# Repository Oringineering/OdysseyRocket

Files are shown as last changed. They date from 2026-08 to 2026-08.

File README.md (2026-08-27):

# Odyssey Rocket

The Odyssey Rocket is a model rocket designed around accessibility, experimentation, and hands-on engineering! Built using household materials, commercially available components, and custom-made parts, it is the perfect project for aspiring engineers without the need for highly specialised equipment. 

The possibilities are endless! This model can be constructed as a relatively low-cost rocket, with the option to incorporate the Orion Flight Computer module capable of recording flight data such as atmospheric pressure and altitude. This modular approach allows the rocket to remain accessible to beginners, whilst giving them the opportunity to develop advanced skills valuable to the workplace that are FREE for students such as SolidWorks*, KiCad, and OpenRocket.



---

## Table of Contents

- [Features](#features)
- [System Architecture](#system-architecture)
- [Components](#components)
- [Quickstart](#quickstart)
- [PCB Design](#pcb-design)
- [Bill of Materials](#bill-of-materials)
- [Project Status](#project-status)
- [Credits](#credits)

---

## Features

- The Orion Flight Computer, a custom nose-cone-mounted PCB that will log acceleration (IMU) and altitude (barometer) data to an onboard MicroSD card, with static-pressure vent holes allowing the BMP388 to measure external atmospheric pressure accurately.
- 3D-printed PLA von Kármán ogive nose cone, custom-fit to a 660 × 60 mm AusPost postal tube body, with a 55 mm shoulder designed to fit securely within the body tube.
- Designed to remain within applicable Western Australian model-rocket operating limits, including a maximum launch mass of 500 g, no more than 25 g of propellant, operation within 5 km of an aerodrome, and an apogee not exceeding 400 ft (121.92 m).

## System Architecture

The Odyssey Rocket consists of several major subsystems:

```text
ODYSSEY ROCKET

├── Airframe
│   ├── Body tube
│   ├── Nose cone
│   └── Fins
│
├── Recovery System
│   ├── Parachute
│   ├── Shock cord
│   └── Nose-cone attachment
│
├── Propulsion
│   └── Commercial model rocket motor
│
└── Orion Flight Computer
    ├── Nose-cone avionics bay
    ├── Static-pressure vent holes
    ├── Arduino Nano
    ├── MPU6050
    ├── BMP388
    ├── MicroSD storage
    └── Power regulation

```

## Components

### Airframe
- AusPost 660 × 60 mm postal tube
- 3D-printed PLA von Kármán nose cone
- Plywood fins

### Recovery System
- Parachute
- Shock cord
- Nose-cone recovery attachment

### Propulsion
- Commercial model rocket motor

 > **Funding Note:** Rocket motors are excluded from the current funding request. The Estes E12-4 remains the selected propulsion option for the OpenRocket design and simulations but will be supplied separately.

### Orion Flight Computer
- Arduino Nano v3
- Adafruit MPU6050
- Adafruit BMP388
- Adafruit MicroSD breakout
- Pololu S13V10F5 5 V step-up/step-down voltage regulator
- Custom Orion Flight Computer PCB
- 3D-printed nose-cone avionics housing
- Static-pressure vent holes for BMP388 atmospheric pressure measurements

### Firmware
- Sensor acquisition
- Relative altitude calculation
- Accelerometer and gyroscope logging
- MicroSD CSV logging
- Serial monitoring

## Quickstart

Odyssey currently includes two different simulations:

- the **Orion Flight Computer simulation**, which runs through Wokwi
- the **Odyssey Flight Simulation**, which runs as an interactive HTML page generated from OpenRocket flight data

---

### Orion Flight Computer Simulation

The Orion Flight Computer can currently be tested virtually using Wokwi.

This simulation is intended to validate the firmware architecture, sensor communication, altitude calculations, and MicroSD data logging before the physical avionics hardware is assembled.

#### Running the Orion Simulation

1. Go to [Wokwi](https://wokwi.com/).
2. Open or create an Arduino Nano project.
3. Use the files contained in the [`FIRMWARE`](FIRMWARE/) folder.
4. Load the supplied:
   - `sketch.ino`
   - `diagram.json`
   - `libraries.txt`
5. Start the simulation using the green play button.
6. Open the Serial Monitor.
7. Orion will initialise the simulated sensors and MicroSD card.
8. Sensor measurements and calculated flight data will begin updating.

A successful startup should produce output similar to:

```text
================================
   ORION FLIGHT COMPUTER
      WOKWI PROTOTYPE
================================

MPU6050: OK
BMP180:  OK
SD Card: OK

Orion ready.
```

> **Note:** The Wokwi simulation uses a BMP180 as a substitute for the BMP388 intended for the final Orion Flight Computer.

Further information can be found in the [Firmware documentation](FIRMWARE/README.md).

---
### Odyssey Rocket Flight Simulation

The Odyssey Rocket Flight Simulation is an interactive browser-based replay generated from the current OpenRocket flight data.

[**Launch the Odyssey Rocket Flight Simulation**](https://oringineering.github.io/OdysseyRocket/SIMULATION/)

The simulation displays:

- Altitude
- Total velocity
- Vertical velocity
- Acceleration
- Thrust
- Lateral distance
- Liftoff
- Motor burnout
- Apogee
- Recovery deployment
- Ground impact

It also includes:

- Play and pause controls
- Restart control
- Timeline scrubbing
- Live flight values
- Flight-event tracking

No additional software is required. The simulation runs directly in a modern web browser.

> **Note:** The Odyssey Rocket Flight Simulation is a visual replay of OpenRocket-generated simulation data. It does not represent measured data from a physical launch.

---

#### Running the Flight Simulation Locally

The simulation can also be run locally.

1. Download or clone the Odyssey Rocket repository.
2. Open the `SIMULATION` folder.
3. Locate `index.html`.
4. Double-click the file.

The simulation should automatically open in your default web browser.

Because the simulation is completely self-contained, it does not require an internet connection once the repository has been downloaded.

## PCB Design
See the [PCB](PCB/Documentation/PCB_OFC_2026-08-23.pdf) and the [Documentation](PCB/Documentation) folder for relevant information.

## Bill of Materials
See [BOM](BOM/) for more information.

## Project Status
AWAITING FUNDING

## Credits
- Niles55 (Reddit) for his tool on modelling Nose Cones. This served as inspiration for me to pursue the Von Karman Ogive after discerning its properties.
- HTM Workshop (YouTube) for his "KiCad Tutorial | Beginning to End" series that gave me a comprehensive understanding on how to make schematics and PCBs. 
- Amazing Automation (YouTube) for his guide on how to place a logo/decal on a PCB.
- LiterallySaltwater (Discord) for providing assistance with coding
- My Dad for his endless knowledge and support :)

*SolidWorks is free for students with an education email address

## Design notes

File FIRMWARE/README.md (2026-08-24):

# Orion Flight Computer Firmware

This folder contains the firmware developed for the **Orion Flight Computer**, the avionics system (+PCB) used in the Odyssey Rocket project.

The firmware is responsible for collecting flight data from the onboard sensors such as altitude, and storing the recorded data on a MicroSD card for later analysis.

The current version has been tested virtually using Wokwi while the physical avionics components are awaiting procurement (subject to funding).

---

## Current Prototype

The current (Wowki) firmware prototype uses:

- **Arduino Nano v3**
  - Runs the Orion firmware and manages sensor communication and data logging

- **MPU6050**
  - 3-axis accelerometer
  - 3-axis gyroscope
  - Communicates with the Arduino using I²C

- **BMP180**
  - Barometric pressure and temperature sensor
  - Used only in the Wokwi simulation
  - Provides pressure data used to calculate relative altitude

- **MicroSD Card Module**
  - Stores flight data as a CSV file
  - Communicates with the Arduino using SPI

> **Note:** The BMP180 is only being used as a simulation substitute because the BMP388 is not currently available as a standard Wokwi component.

---

## Final Hardware

The intended Orion Flight Computer hardware uses:

- Arduino Nano v3
- Adafruit MPU6050
- Adafruit BMP388
- Adafruit MicroSD breakout
- Pololu S13V10F5 5 V step-up/step-down voltage regulator

The BMP388 will replace the BMP180 used in the simulation.

The Pololu regulator and other power components are not represented in the Wokwi simulation because the current simulation is intended primarily to validate the firmware and data flow.

---

## Firmware Functions

The current firmware performs the following functions:

- Initialises the MPU6050
- Initialises the barometric pressure sensor
- Initialises the MicroSD card
- Establishes a reference altitude during startup
- Reads acceleration in the X, Y and Z directions
- Reads angular velocity from the gyroscope
- Reads atmospheric pressure
- Reads temperature
- Calculates relative altitude
- Outputs live data through the Serial Monitor
- Records flight data to a CSV file
- Periodically flushes data to the MicroSD card to reduce the risk of data loss

---

## Data Flow

The Orion firmware follows the general data flow shown below:

```text
MPU6050 ─────────────┐
                     │
Barometer ───────────┼──> Arduino Nano
                     │        │
                     │        ├──> Flight calculations
                     │        │
                     │        ├──> Serial Monitor
                     │        │
                     │        └──> MicroSD Card
                     │
Power System ────────┘

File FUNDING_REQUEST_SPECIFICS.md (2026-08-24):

# Funding Breakdown
----

| Cost category | USD |
| -- | --: |
| Electronic components | **$43.78** |
| Bare PCB order | **$12.00** |
| Component/PCB shipping + VAT | **$87.54** |
| Estes E12-4 (motor) + Australian postage | **$50.91** |
| Parachute | **$15.00** |
| **Overall total so far** | **$209.23 USD** |

>**DISCLAIMER**:
A majority of these parts are accessible from the US only and that even despite the tariffs and shipping, the US providers are cheaper than the Australian providers upon closer inspection. As such, the shipping and tariffs appear extortionate on paper but compared to the Australian parts that I would have to source interstate, they are cheaper than sourcing them locally. 

----

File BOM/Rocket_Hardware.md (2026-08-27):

| No. | Qty | Comment | Specification | Manufacturer / Supplier | Supplier Part | Notes |
| --: | --: | --- | --- | --- | --- | ----- |
| 1 | 1 | Australia Post Mailing Tube with Sleeve | 660 × 60 mm | Australia Post | Mailing Tube with Sleeve Kraft Medium | Main rocket body |
| 2 | 1 | M6 RivNut | M6 threaded insert | Kincrome / Bunnings | Kincrome M6 20 Piece RivNut Set | Installed into the reinforced nose-cone bulkhead as the recovery attachment insert |
| 3 | 1 | M6 Eye Nut | M6 | Pinnacle / Bunnings | Pinnacle M6 Eye Nut | Threads into the M6 RivNut and provides the shock-cord attachment point |
| 4 | 1 | Premium BC Grade Plywood Sheet | 1200 × 810 × 3 mm | Bunnings | Project Panel Plywood | Used for fins and centering ring; 3 mm thickness matches the current OpenRocket design |
| 5 | 1 | SkyAngle Classic 20 Parachute | 20 in / 50.8 cm | SkyAngle / CS Rocketry | SkyAngle Classic 20 | Primary recovery parachute |
| 6 | 1| Shock Cord | 3 mm diameter | eBay | 3 mm Shock Cord | Connects the nose cone, parachute, and rocket body recovery assembly |

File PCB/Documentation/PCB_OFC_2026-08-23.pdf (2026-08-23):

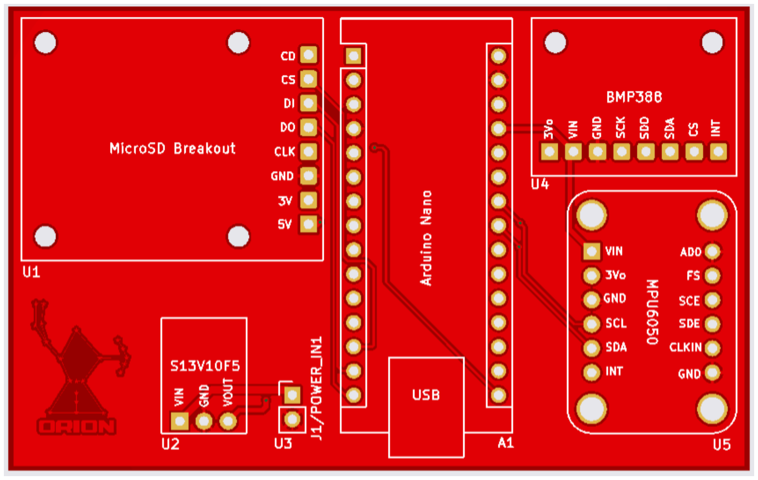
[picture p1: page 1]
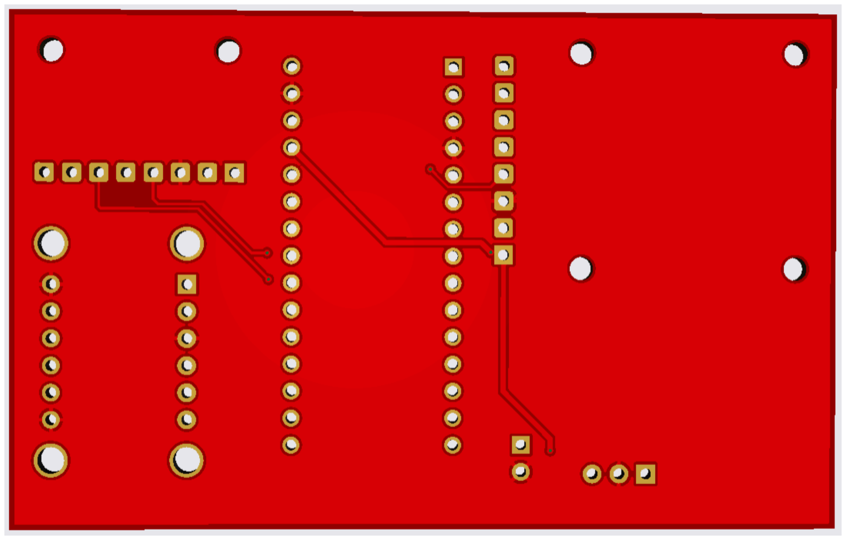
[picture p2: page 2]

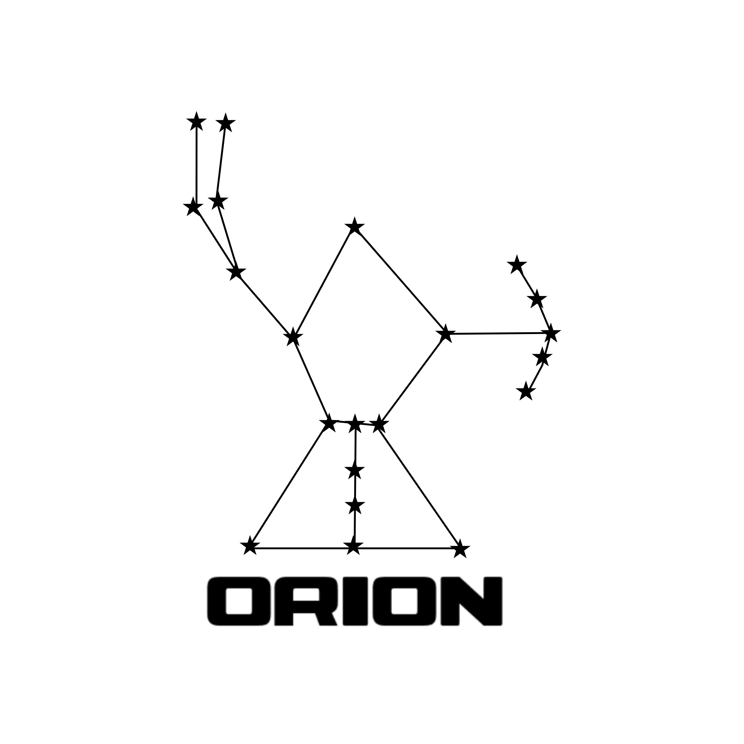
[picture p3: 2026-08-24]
ASSETS/orion.png

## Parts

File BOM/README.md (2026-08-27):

# Odyssey Rocket Bill of Materials

The estimated total cost of the Odyssey Rocket, including the Orion Flight Computer, PCB fabrication, propulsion system, recovery system, primary rocket hardware, and shipping costs, is approximately:

# **US$250**

| Item | Cost |
|---|---:|
| Orion electronic components | US$54.65 |
| Orion PCB fabrication | US$12.00 |
| Electronics / PCB shipping and VAT | US$87.54 |
| Australia Post 660 × 60 mm postal tube | ~US$3.60 |
| 3 mm plywood sheet | ~US$13.60 |
| SkyAngle Classic 20 in parachute | US$20.00 |
| 3.5 m shock cord | ~US$6.40 |
| Kincrome M6 RivNut set | ~US$9.40 |
| Pinnacle M6 eye nut | ~US$0.86 |
| Hardware shipping costs | ~US$46.00 |
| **Estimated Total Project Cost** | **~US$250** |

Prices may vary depending on supplier availability, shipping costs, and exchange rates.
~ Excludes Rocket Motor (will supply myself with one)

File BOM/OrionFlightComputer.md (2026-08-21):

| No. | Qty | Comment | Designator | Footprint | Value | Manufacturer Part | Manufacturer | Supplier Part | Supplier |
| --: | --: | --- | --- | --- | --- | --- | --- | --- | --- |
| 1 | 1 | Arduino Nano v3 | **A1** | `Arduino_Nano_v3.x_MODIFIED` | Arduino Nano | **A000005** | Arduino | A000005 | Arduino  |
| 2 | 1 | MicroSD Card Breakout Board | **U1** | `ADAFRUIT_MICROSD` | MicroSD Breakout | **254** | Adafruit | 254 | Adafruit |
| 3 | 1 | 5 V Step-Up/Step-Down Regulator | **U2** | `POLOLU_S13V10F5` | S13V10F5 | **4083** | Pololu | 4083 | Pololu |
| 4 | 1 | BMP388 Barometric Pressure Sensor Breakout | **U3** | `ADAFRUIT_BMP388` | BMP388 | **3966** | Adafruit | 3966 | Adafruit |
| 5 | 1 | MPU6050 Accelerometer/Gyroscope Breakout | **U4** | `ADAFRUIT_MPU6050` | MPU6050 | **3886** | Adafruit | 3886 | Adafruit |
| 6 | 1 | 2-pin 2.54 mm Power Input Header | **J1** | `PinHeader_1x02_P2.54mm_Vertical`* | 1×02 2.54 mm | **B-2100S02P-A110** | Ckmtw | **C124375** | LCSC |

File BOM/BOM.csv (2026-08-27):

 | Item Name | Qty | Price (total) (USD) | Item link | Notes
0 | Arduino Nano v3 (A000005) | 1 | 14.30 | https://www.amazon.com.au/Arduino-Elegoo-ATmega328P-Without-Compatible/dp/B077272KMZ/ | Main Orion Flight Computer microcontroller.
1 | Adafruit MPU6050 (Product 3886) | 1 | 12.95 | https://www.adafruit.com/product/3886 | 6-DoF accelerometer and gyroscope for Orion.
2 | Adafruit BMP388 (Product 3966) | 1 | 9.95 | https://www.adafruit.com/product/3966 | Barometric pressure sensor / altimeter for Orion.
3 | Adafruit MicroSD Card Breakout Board+ (Product 254) | 1 | 7.50 | https://www.adafruit.com/product/254 | MicroSD flight-data logging module.
4 | Pololu S13V10F5 5V Step-Up/Step-Down Regulator | 1 | 9.95 | https://www.pololu.com/product/4083 | 5 V regulator for Orion Flight Computer.
5 | Orion Flight Computer PCB fabrication | 1 | 12.00 | https://jlcpcb.com/ | Bare 2-layer PCB fabrication estimate.
6 | Electronics / PCB shipping and VAT | 1 | 87.54 |  | Combined shipping/VAT estimate from the current project budget.
7 | Australia Post Mailing Tube with Sleeve Kraft Medium (660 × 60 mm) | 1 | 3.60 | https://auspost.com.au/shop/product/mailing-tube-with-sleeve-kraft-medium-60mm-single-10005221-s | Main rocket body. Approximate USD conversion from AUD.
8 | 3 mm birch / project plywood sheet | 1 | 13.60 | https://www.bunnings.com.au/1200-x-810mm-3mm-plywood-pine-premium-bc-grade_p0340268 | Used for fins and centering ring.
9 | SkyAngle Classic 20 parachute | 1 | 20.00 | https://www.csrocketry.com/recovery-supplies/skyangle/chutes/20-skyangle-classic.html | 20 in recovery parachute.
10 | 3 mm shock cord, 3.5 m | 1 | 6.40 | https://www.ebay.com.au/itm/275682561156 | Recovery shock cord.
11 | M6 RivNut | 1 | 9.40 | https://www.bunnings.com.au/kincrome-m6-20-piece-rivnut-set_p5910351 | Final recovery attachment hardware.
12 | M6 eye fitting / eye nut | 1 | 0.86 | https://www.bunnings.com.au/pinnacle-m6-eye-nut_p0091162 | Threads into the M6 RivNut.
13 | Hardware Shipping Costs | 1 | 46.00 |  | Additional hardware shipping costs.
14 | Known Project Total (Approximate USD Value) | 1 | 250

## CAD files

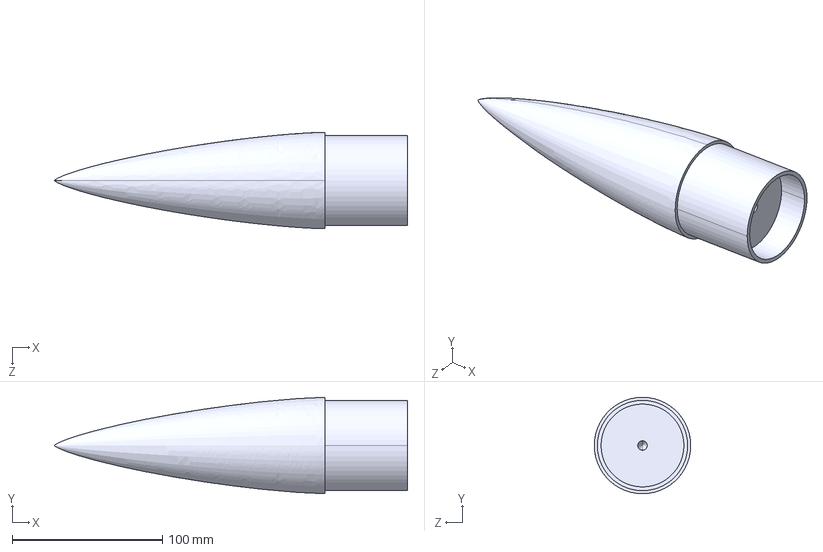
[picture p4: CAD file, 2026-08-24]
CAD/NoseCone.STEP
235.0 x 64.2 x 64.2 mm

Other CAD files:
CAD/NoseCone.SLDPRT

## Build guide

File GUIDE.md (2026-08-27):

# GUIDE

This guide outlines how to construct the **Odyssey Rocket** from scratch.

Odyssey has been designed around relatively accessible materials and components, with most custom parts either being 3D printed or manufactured using basic tools.

The **Orion Flight Computer** is optional and can be incorporated if onboard flight-data logging is desired.

> **Note:** Always follow the instructions supplied with commercially manufactured rocket motors and check the relevant local regulations before launching.

---

## 1. Required Components

Before beginning construction, gather the required components listed in the project Bills of Materials.

### Rocket Hardware

- Australia Post 660 × 60 mm postal tube
- 3 mm birch plywood sheet
- 3D-printed PLA nose cone
- M6 RivNut
- M6 eye fitting
- Shock cord
- SkyAngle Classic 20 parachute
- Estes E12-4 model rocket motor

> **Funding Note:** Rocket motors are excluded from the current funding request. The Estes E12-4 remains the selected propulsion option for the OpenRocket design and simulations but will be supplied separately.

Further information can be found in the [Rocket Hardware BOM](BOM/Rocket_Hardware.md).

### Orion Flight Computer

If the avionics system is being used, the primary components are:

- Arduino Nano v3
- Adafruit MPU6050
- Adafruit BMP388
- Adafruit MicroSD breakout
- Pololu S13V10F5 voltage regulator
- Orion Flight Computer PCB

Further information is available in the [Firmware](FIRMWARE/) and [PCB](PCB/) folders.

---

## 2. Prepare the Body Tube

The main airframe uses an **Australia Post 660 × 60 mm postal tube**.

Before attaching anything to the tube:

- Check that the tube is straight and undamaged.
- Test the fit of the nose cone shoulder.
- Mark the fin positions.
- Mark the location of the motor-mount assembly.

The nose cone should fit securely into the tube without requiring excessive force.

---

## 3. Manufacture the Fins

Odyssey uses three birch-plywood fins based on the current OpenRocket model.

### Fin Dimensions

| Parameter | Dimension |
|---|---:|
| Number of fins | 3 |
| Root chord | 70 mm |
| Tip chord | 55 mm |
| Height | 40 mm |
| Sweep length | 26 mm |
| Sweep angle | 33° |
| Thickness | 3 mm |
| Root fillet radius | 2 mm |
| Material | Birch plywood |
| Cross-section | Rounded |

The fins use **through-the-wall tabs**, allowing the fins to pass through the postal tube and connect with the internal motor-mount region.

### Fin Tab Dimensions

| Parameter | Dimension |
|---|---:|
| Tab length | 70 mm |
| Tab height | 17 mm |
| Tab position | 0 mm |
| Reference | Top of parent component |

The easiest method is to manufacture one accurate fin first and use it as a template for the remaining two.

Once all three fins have been cut, stack them together and lightly sand the edges until they are approximately identical.

The leading and trailing edges can also be rounded slightly to better represent the current OpenRocket model.

---

## 4. Mark and Cut the Fin Slots

The three fins should be evenly spaced around the body tube.

Because there are three fins:

**360° ÷ 3 = 120°**

Mark three longitudinal reference lines around the lower section of the body tube, each separated by approximately **120°**.

Using the fin tabs as a reference, mark and cut the corresponding slots through the body tube.

The slots should allow the 3 mm plywood tabs to pass through without excessive force while avoiding unnecessary clearance.

Test-fit all three fins before applying adhesive.

---

## 5. Install the Centering Ring

The motor-mount assembly uses one birch-plywood centering ring.

### Centering Ring Dimensions

| Parameter | Dimension |
|---|---:|
| Thickness | 3 mm |
| Outer diameter | 55.6 mm |
| Inner diameter | 25.8 mm |
| Material | Birch plywood |

The centering ring is positioned approximately **5 mm forward of the bottom of the motor-mount tube**.

Its purpose is to keep the motor-mount tube centred within the main airframe and provide additional support at the rear of the rocket.

Before gluing:

- Check that the inner diameter fits around the motor-mount tube.
- Check that the outer diameter fits within the main body tube.
- Confirm that the motor mount remains centred.
- Confirm that the fin tabs do not interfere with the centering ring.

Once aligned, secure the centering ring to the motor-mount assembly using an appropriate adhesive.

---

## 6. Attach the Fins

Insert each fin tab through its corresponding slot in the body tube.

Check that:

- The root chord sits flat against the outside of the body tube.
- The tab is fully inserted.
- The fin is parallel with the rocket centreline.
- The fin is not twisted.
- All three fins begin at the same axial position.
- Each fin is approximately 120° from the next.

Once satisfied with the alignment, secure the fins using an adhesive appropriate for plywood and cardboard.

A small external fillet can then be formed along each fin root.

Allow the adhesive to cure fully before continuing.

---

## 7. Print the Nose Cone

The Odyssey nose cone is a custom **von Kármán / Haack-series nose cone** created in SolidWorks.

### Nose Cone Dimensions

| Parameter | Dimension |
|---|---:|
| Nose cone length | 180 mm |
| Maximum outer diameter | 64.2 mm |
| Shoulder length | 55 mm |
| Shoulder outer diameter | 60.15 mm |
| Shoulder wall thickness | 2.5 mm |
| Internal bulkhead thickness | 7.5 mm |
| Central boss diameter | 20 mm |
| Recovery hole diameter | 6.4 mm |

The nose cone should be printed vertically with the **shoulder placed on the build plate and the nose tip facing upward**.

The current model was prepared using a **0.16 mm layer height**.

Support should be generated underneath the internal bulkhead. A support blocker can be used around the central recovery attachment so that unnecessary support material does not fill the attachment region.

Once printing is complete, inspect the nose cone for:

- Layer separation
- Cracks
- Incomplete walls
- Poorly formed support surfaces
- Damage around the internal bulkhead
- Damage around the central boss
- Poor fit between the shoulder and body tube

The shoulder should fit securely within the postal tube without requiring excessive force.

If the Orion Flight Computer is being installed, the nose cone must also provide sufficient internal clearance for the avionics housing and static-pressure vent holes described later in this guide.

---

## 8. Install the Recovery Attachment

The nose cone contains a reinforced internal recovery structure consisting of:

- A 7.5 mm internal bulkhead
- A central reinforced boss
- Four reinforcing ribs
- A central recovery hole

An earlier design considered embedding an eye bolt during the 3D-printing process.

This was abandoned because the bolt would have needed to be inserted from underneath while the shoulder remained fixed to the build plate. The metal fastener could also have interfered with the moving print head.

The final design instead uses an **M6 RivNut** installed after printing.

### Installing the M6 RivNut

The current CAD hole is approximately **Ø6.4 mm**.

This is suitable for M6 bolt clearance, but the outside diameter of an M6 RivNut is larger. The printed hole must therefore be carefully enlarged after printing.

> **Important:** The required hole diameter depends on the specific M6 RivNut being used. Measure the selected RivNut or follow the manufacturer's recommended installation-hole diameter before drilling.

Enlarge the hole gradually and keep the drill centred through the boss and bulkhead.

Once the hole has been prepared:

1. Insert the M6 RivNut.
2. Install it using a suitable RivNut setting tool.
3. Confirm that it is seated firmly against the printed boss.
4. Thread the M6 eye fitting into the RivNut.
5. Tighten it securely without applying enough force to crack or crush the PLA.

The finished attachment should be manually pull-tested before flight.

---

## 9. Install the Shock Cord

The current OpenRocket model specifies a shock-cord length of:

**350 cm (3.5 m)**

The current simulation specifies approximately **2 mm round elastic cord**.

Attach one end of the shock cord securely to the **M6 eye fitting** installed in the nose cone.

Ensure that:

- The attachment is secure.
- The cord is not damaged or frayed.
- The cord does not rub against sharp edges.
- There is enough length for the nose cone and recovery system to separate safely.

If a different diameter or material is used in the finished rocket, update the OpenRocket model accordingly.

---

## 10. Attach the Parachute

The current recovery system uses a:

**SkyAngle Classic 20**

with an approximate diameter of:

**20 in / 50.8 cm**

The recovery arrangement is approximately:

```text
Nose Cone
    │
M6 RivNut
    │
M6 Eye Fitting
    │
Shock Cord
    │
Parachute Attachment
    │
Rocket Body
```

Attach the parachute fitting securely to the shock-cord recovery assembly.

Before packing the parachute:

- Check that the suspension lines are not tangled.
- Inspect the canopy for damage.
- Confirm that all attachment points are secure.
- Make sure the parachute opens freely.
- Confirm that the packed parachute fits within the body tube without excessive compression.

---

## 11. Motor System

The current OpenRocket configuration uses an:

**Estes E12-4**

This is a commercially manufactured 24 mm model rocket motor with a four-second delay.

The motor should only be installed when the completed rocket is being prepared for launch.

Follow the manufacturer's instructions for installation, retention and ignition.

---

## 12. Assemble the Orion Flight Computer

The Orion Flight Computer is an optional avionics subsystem designed to record flight data for post-flight analysis.

The PCB integrates:

- Arduino Nano v3
- Adafruit MPU6050
- Adafruit BMP388
- Adafruit MicroSD breakout
- Pololu S13V10F5 voltage regulator
- Power input connector

PCB design and manufacturing information can be found in the [PCB](PCB/) folder.

### PCB Manufacturing

The bare PCB can be manufactured using the fabrication files included in the repository.

If only **bare PCB manufacturing** is selected when ordering the board, the modules and connectors must be installed manually once the PCB arrives.

If an appropriate assembly service has been configured with the manufacturer, some components may instead arrive pre-assembled.

The current Orion design primarily uses modules and through-hole headers and is therefore suitable for manual assembly.

### Component Placement

| Designator | Component |
|---|---|
| A1 | Arduino Nano v3 |
| U1 | Adafruit MicroSD breakout |
| U2 | Pololu S13V10F5 regulator |
| U3 | Adafruit BMP388 |
| U4 | Adafruit MPU6050 |
| J1 | Power input header |

Before soldering:

- Confirm that each component matches its intended footprint.
- Check component orientation.
- Ensure that header pins pass cleanly through the PCB.
- Make sure each module sits level.
- Check that nothing has been inserted backwards.

### Soldering

Unless the PCB has been supplied with the required hardware already assembled, the modules and headers must be soldered manually.

For each connection:

1. Insert the component or header.
2. Confirm its orientation.
3. Hold the component square to the PCB.
4. Heat both the pad and pin with the soldering iron.
5. Feed a small amount of solder into the joint.
6. Remove the solder.
7. Remove the iron.
8. Allow the joint to cool without moving the component.

Inspect the completed PCB for:

- Missing joints
- Poor wetting
- Excess solder
- Solder bridges
- Loose pins
- Incorrect component orientation

Do not connect a battery until the PCB has been inspected.

---

## 13. Bench Test the Orion Flight Computer

The Orion Flight Computer should be tested using a computer and USB connection **before testing the battery and Pololu power system**.

USB is useful for the first testing stage because it provides both power and serial communication with the Arduino Nano.

### Required Equipment

- Completed Orion PCB
- Arduino Nano
- Computer
- USB data cable
- MicroSD card
- Arduino IDE
- Orion firmware

> **Important:** Make sure the USB cable supports data transfer. Some cables only provide power.

### Step 1 - Inspect the PCB

Before connecting USB:

- Inspect both sides of the PCB.
- Check for solder bridges.
- Check for loose solder fragments.
- Confirm that all modules are installed in the correct orientation.
- Check the power rails for obvious shorts using a multimeter where possible.

Do not connect the external battery at this stage.

### Step 2 - Connect the Nano Using USB

Connect the Arduino Nano directly to the computer.

During this stage, USB provides power and serial communication.

Avoid connecting the external battery simultaneously until the final power architecture has been properly verified.

### Step 3 - Configure Arduino IDE

Open Arduino IDE.

Select:

**Tools → Board → Arduino Nano**

Select the appropriate processor and then select the Nano's serial port under:

**Tools → Port**

### Step 4 - Test the Nano and Serial Connection

Upload a simple serial-output sketch.

Open:

**Tools → Serial Monitor**

The current Orion firmware uses:

**115200 baud**

Confirm that the Nano can send data reliably to the computer.

### Step 5 - Test the I²C Bus

The MPU6050 and BMP388 share the I²C bus.

Run an I²C scanner and confirm that both sensors are detected.

This provides a basic check of:

- SDA
- SCL
- Sensor power
- Ground
- I²C communication

### Step 6 - Test the MPU6050

Run a basic MPU6050 test and confirm that the following values appear:

- X acceleration
- Y acceleration
- Z acceleration
- X angular velocity
- Y angular velocity
- Z angular velocity

Move and rotate the PCB and confirm that the values change accordingly.

### Step 7 - Test the BMP388

Run a BMP388 test and confirm that the following values are available:

- Atmospheric pressure
- Temperature
- Calculated altitude

The measurements should remain reasonably stable when the PCB is stationary.

### Step 8 - Test the MicroSD Card

Insert a formatted MicroSD card.

Run an SD test that:

1. Initialises the card.
2. Creates a test file.
3. Writes several lines.
4. Closes the file.

Remove the card and check the file on the computer.

### Step 9 - Upload the Complete Orion Firmware

Once each subsystem works independently, upload the complete Orion firmware.

A successful startup should produce output similar to:

```text
================================
   ORION FLIGHT COMPUTER
================================

MPU6050: OK
BMP388:  OK
SD Card: OK

Orion ready.
```

### Step 10 - Perform a Logging Test

Allow Orion to run for several minutes.

During the test:

- Move and rotate the PCB.
- Raise and lower it.
- Monitor the Serial output.
- Allow data to be recorded to the MicroSD card.

Afterward, check the generated CSV and confirm that:

- Timestamps increase correctly.
- Acceleration measurements were recorded.
- Gyroscope measurements were recorded.
- Pressure measurements were recorded.
- Altitude measurements were recorded.

### Step 11 - Test the External Power System

Once USB testing has succeeded, disconnect USB.

Connect the intended battery to the Pololu regulator.

Measure the regulator output with a multimeter before connecting the complete system.

The expected regulated output is approximately:

**5 V**

Once verified, power Orion using the intended flight power system and confirm that its behaviour matches the USB test.

---

## 14. Build the Nose-Cone Avionics Bay Housing

The Orion Flight Computer should not be installed as a bare PCB.

For Odyssey, Orion is housed within the **nose cone** using a dedicated **3D-printed avionics sled or enclosure**.

The housing should:

- Fit securely within the available internal volume of the nose cone.
- Hold the Orion PCB firmly using standoffs or spacers.
- Prevent the flight computer from moving during launch and recovery.
- Remain clear of the M6 RivNut, M6 eye fitting, internal bulkhead, and reinforcing ribs.
- Provide clearance for the MicroSD card.
- Provide clearance for the Arduino Nano USB connector where practical.
- Allow wiring to pass through without being crushed or sharply bent.
- Avoid covering the BMP388 pressure sensor.
- Remain removable for testing, maintenance, and firmware updates.

A simple removable sled is preferred over a separate PVC tube because it can be shaped specifically around the nose-cone geometry while minimising additional mass and lost internal volume.

Before finalising the housing, confirm that the complete Orion assembly fits inside the nose cone without interfering with the recovery attachment or preventing the nose cone from seating correctly in the body tube.

---

## 15. Barometer Ventilation

The Orion Flight Computer uses a **BMP388 barometric pressure sensor** to estimate altitude.

Because Orion is housed inside the nose cone, the avionics compartment must not be completely sealed. Several small **static-pressure vent holes** should therefore be added through the nose-cone wall adjacent to the avionics bay.

The vent holes should:

- Be distributed around the circumference of the nose cone where practical.
- Be positioned adjacent to the Orion avionics bay.
- Provide direct pressure equalisation between the internal avionics compartment and the surrounding atmosphere.
- Remain clear of the M6 recovery attachment, internal bulkhead, and reinforcing ribs.
- Avoid being obstructed by the avionics housing.
- Avoid locations immediately beside large protrusions or regions of heavily disturbed airflow where practical.

The vent holes should be added only after the final position of the Orion Flight Computer and its housing has been established.

These openings allow the internal pressure around the BMP388 to follow changes in external atmospheric pressure more closely, improving the accuracy of altitude measurements.

After the vent holes have been added, check that they are clean, unobstructed, and open directly into the avionics cavity.

---

## 16. Install Orion in the Nose Cone

Once the avionics housing has been assembled, bench-tested, and checked for clearance, install it securely within the nose cone.

Ensure that:

- The housing cannot move freely.
- The PCB remains fixed within the housing.
- The BMP388 remains exposed to the ventilated internal cavity.
- The static-pressure vent holes are not blocked by the housing, wiring, or PCB.
- The MicroSD card remains accessible where practical.
- Wiring cannot contact sharp edges.
- The avionics bay does not interfere with the M6 RivNut, eye fitting, internal ribs, or recovery attachment.
- The nose cone can still seat correctly within the body tube.
- The assembly can be removed for maintenance where practical.

---

## 17. Final Assembly

Once the major components have been completed, inspect the entire rocket.

Check:

- Nose cone fit
- Body tube condition
- Fin alignment
- Fin attachment
- Centering ring
- Motor mount
- RivNut recovery attachment
- Shock cord
- Parachute
- Orion nose-cone avionics bay, if installed
- Static-pressure vent holes clear and unobstructed

Nothing inside the rocket should move freely during flight.

---

## 18. Update the OpenRocket Model

The final physical rocket will differ slightly from the original OpenRocket model.

Before launch, weigh the completed rocket and update the simulation where necessary.

Important values include:

- Total mass
- Centre of gravity
- Fin geometry
- Nose cone dimensions
- Recovery-system mass
- Orion Flight Computer mass
- Motor selection

The current OpenRocket configuration shown during development produces approximately:

| Parameter | Current Simulation |
|---|---:|
| Motor | Estes E12-4 |
| Apogee | 121.28 m |
| Maximum velocity | 38.74 m/s |
| Maximum acceleration | 67.35 m/s² |
| Stability | 1.71 cal |

These values should be treated as **simulation results rather than guaranteed flight performance**.

Re-run the simulation using the final measured configuration before flight.

---

## 19. Ground Testing

Before flight, complete basic ground testing.

This should include:

- Nose cone fit testing
- Recovery attachment pull testing
- Shock-cord inspection
- Parachute deployment testing
- Structural inspection
- Orion power-on testing
- Sensor initialisation
- MicroSD logging verification
- Avionics-bay retention testing
- Static-pressure vent-hole inspection
- BMP388 pressure-response testing with Orion installed in the ventilated nose cone

The Wokwi simulation validates the general firmware architecture but does not replace testing of the physical Orion hardware.

---

## 20. Launch Preparation

Once construction, simulation and ground testing have been completed, the rocket can progress to launch preparation.

Before launching:

- Check weather conditions.
- Check applicable fire restrictions.
- Confirm that the launch location is suitable.
- Check applicable model rocket and aviation requirements.
- Inspect the rocket immediately before flight.
- Confirm that the nose-cone pressure vents remain unobstructed.
- Follow the motor manufacturer's preparation and ignition instructions.

---

# Construction Complete

At this stage, the Odyssey Rocket should be mechanically assembled and ready for final testing and launch preparation.

Additional project information is available in:

- [Main README](README.md)
- [Bill of Materials](BOM/)
- [Firmware](FIRMWARE/)
- [PCB](PCB/)
- [CAD](CAD/)

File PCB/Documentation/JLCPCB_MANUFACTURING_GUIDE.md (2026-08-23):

# JLCPCB Manufacturing Guide
----

This document outlines the process used to prepare and manufacture the Orion Flight Computer PCB through JLCPCB.

----
## Note:

The only extra thing I changed was the colour of the PCB because red suited the decal on the PCB better than the standard green did.

# 1. Final Checks in KiCad

Before generating fabrication files, ensure the PCB is complete and passes all required checks.

## Final checklist

- Run the **Design Rules Checker (DRC)** - you may experience errors such as:
  - setting silkscreen text to 0.7 mm when a larger size was preferable for manufacturing
  - isolated copper fill regions
  - inadequate thermal-relief connections
  - overly wide tracks interfering with nearby pads
  - silkscreen elements overlapping solder-mask regions

- Confirm that there are **0 unconnected items**
- Confirm that there are **0 critical violations**
- Refill all copper zones using `B`
- Check all the GND pads are properly connected to the copper pours
  - If they aren't connected, try going over the schematic or attempt a copper pour again.
- Verify all tracks are routed
- Verify track widths (different track types support different currents and typically correspond to their functionality on the PCB):
  - Signal tracks: **0.25 mm**
  - +5 V tracks: **0.50 mm**
  - VIN_RAW / main input power: **0.75 mm**
- Check silkscreen text does not overlap pads or solder-mask openings
- Check the board outline on `Edge.Cuts` is fully closed
- Inspect the design in KiCad's **3D Viewer**
- Verify the orientation of all breakout modules
- Confirm USB and MicroSD access is unobstructed
- Check all custom footprint pin mappings against the schematic

# 2. Generate Gerber Files

In KiCad PCB Editor:

**File → Fabrication Outputs → Gerbers (.gbr)**

Select the required layers.

For this 2-layer PCB, the important layers are typically:

- `F.Cu`
- `B.Cu`
- `F.SilkS`
- `B.SilkS` if used
- `F.Mask`
- `B.Mask`
- `Edge.Cuts`

Generate the Gerber files into a dedicated fabrication folder.

Example:

```text
PCB/Fabrication/Gerbers/

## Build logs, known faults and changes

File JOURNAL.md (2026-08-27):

# Odyssey Rocket

> **A model rocket prototype built from accessible materials, custom-designed components, and a completely self-developed avionics system.**

| Project Information | Details |
| --- | --- |
| **Author** | Orin Gibson |
| **Project** | Odyssey Rocket |
| **Description** | A rocket prototype... but I knew nothing about rockets or the software that can be utilised to make one. |
| **Creation Date** | 01/08/2026 |
| **Total Time Spent** | **~37 hours** |

---

# Day 1 — Learning Bit by Bit
### ⏱️ 35 minutes

I spent the first day familiarising myself with industry software such as **SolidWorks**, preparing myself for the CAD work required for components such as the nose cone and other internal components that would later be 3D printed.

<p align="center">
  
</p>

<p align="center">
  <em>Beginning the process of learning CAD and 3D modelling.</em>
</p>

---

# Day 2 — Body Schematics and Design
### ⏱️ 1 hour 39 minutes

I introduced myself to **OpenRocket**, an open-source program that lets you visualise a rocket and run simulations on it.

I managed to grasp a basic understanding of how the software works: you select the components you want for your rocket while determining the appropriateness of certain features to optimise factors such as:

- **Stability**
- **CP — Centre of Pressure**
- **CG — Centre of Gravity**
- Aerodynamic performance

Something I initially struggled with was producing a stable rocket.

From what I later discerned from [this resource on model rocket stability](https://www.spacecad.com/posts/model-rocket-stability-prediction/), my stability calibre was not optimal and was one reason why the rocket was underperforming in simulations.

I initially had a stability value above **2.8 cal**, believing that a higher calibre automatically meant a more stable rocket. However, excessive stability can also result in poorer aerodynamic behaviour.

<p align="center">
  
</p>

<p align="center">
  <em>An early OpenRocket iteration of Odyssey.</em>
</p>

---

# Day 3 — Functionality Refinements
### ⏱️ 1 hour 28 minutes

This day was spent rectifying the blunders made on Day 2.

With newfound awareness and a strong resolve to improve upon yesterday's faults, I put my head down and got working.

This [OpenRocket tutorial series](https://www.youtube.com/watch?v=oqe0lTp1WH0&list=PLulIhjxR7aZQ4coWt7MRHb4xt9wz0Fz6h) really made me think.

I had no idea about the purpose of a **shoulder**, which connects the nose cone to the rocket body, or **fin tabs**, which extend into the rocket body and provide a more secure structural connection.

With these implementations taken into consideration, my model became **far more stable**, and it was genuinely satisfying to see the design improve.

### Nose Cone Constraints

Another thing I had not considered was the length of my nose cone.

Originally, I had it set to approximately **22 × 6 cm**, but realised that if I were to use a local 3D printer, these dimensions might exceed its available build height once the **5.5 cm shoulder** was included.

A total length of approximately **27.5 cm** exceeds the build volume of many basic entry-level printers.

My original reasoning for the 22 cm nose cone was to maintain approximately a **3:1 nose-cone length-to-diameter ratio** to reduce drag. However, this was less important than I initially thought for the relatively low-speed flight regime being targeted.

<p align="center">
  
</p>

<p align="center">
  <em>Refined OpenRocket design after improving stability and dimensional constraints.</em>
</p>

With these limitations in place, I settled on a nose cone length of **18 cm**.

It will not mitigate drag to the same extent as the original design, but it remains sufficiently long for the intended application.

The total length, including the shoulder, became approximately **23.5 cm**, allowing it to fit within an entry-level 3D printer with a maximum build height around **24.5–25 cm**.

---

# Day 4 — Schematic Design
### ⏱️ 4 hours 16 minutes

I started my work on **KiCad** today.

KiCad was a completely new challenge because electronics design is far from my existing strong suit. Nonetheless, it became a journey filled with some amazing discoveries.

To begin, I watched a tutorial series explaining how to create a schematic in KiCad.

I started by assembling the individual components:

- **MPU6050 IMU**
- **Adafruit BMP388 barometer**
- **Arduino Nano v3**

For the Arduino Nano, I also modified one of the pin definitions to prevent unnecessary errors during KiCad's **Electrical Rules Check (ERC)**.

<p align="center">
  
</p>

<p align="center">
  <em>Early development of the Orion Flight Computer schematic.</em>
</p>

I felt outrageously proud because I never expected to learn this process.

It feels rather good to now be familiar with all of this new terminology and these completely unfamiliar engineering processes.

---

# Day 5 — Schematic Improvement
### ⏱️ 3 hours 33 minutes

I realised that my flight computer did not yet contain all of the components required to perform the functions I wanted.

It was missing:

- a **MicroSD module** for flight-data storage
- a **voltage regulator** for stable power distribution

The new additions consisted of:

- **Adafruit MicroSD Breakout Board+**
- **Pololu 5V Step-Up/Step-Down Voltage Regulator S13V10F5**

My reasoning for choosing these products was largely their excellent documentation and accessibility compared with alternatives that could be significantly harder to source.

## Orion Flight Computer

I also finally settled on a name:

### **Orion Flight Computer**

Why Orion?

I loved space a lot as a kid, and **Orion** happens to be remarkably close to my own name, **Orin**.

The flight computer contains:

| Component | Purpose |
| --- | --- |
| **Arduino Nano v3** | Main microcontroller |
| **MPU6050 IMU** | Acceleration and rotational measurements |
| **BMP388 Barometer** | Atmospheric pressure and altitude measurements |
| **MicroSD Module** | Flight-data logging |
| **S13V10F5 Regulator** | Voltage regulation and power management |

I based the component schematics primarily on technical designs and manufacturer documentation, including Adafruit's respective Eagle files and component repositories.

After each individual component was created, I incorporated it into the overall schematic.

This marked a successful implementation, although there were still some underlying mistakes that would need to be corrected later.

<p align="center">
  
</p>

<p align="center">
  <em>An intermediate version of the Orion Flight Computer schematic.</em>
</p>

---

# Day 6 — Schematic Finalisation
### ⏱️ 2 hours 10 minutes

I revised the individual schematics and realised that the original IMU I had selected was not documented sufficiently for me to confidently reproduce its physical dimensions.

I therefore settled on the **Adafruit MPU6050 IMU**.

This required me to redo the IMU schematic because Adafruit's breakout contains **12 pins**, with six on either side.

With the schematic finalised, I shifted my focus toward creating the individual **PCB footprints** for each component.

Each component was then refined so that the schematic could be transferred effectively into the final PCB design.

<p align="center">
  
</p>

<p align="center">
  <em>Finalised MPU6050 schematic symbol and pin configuration.</em>
</p>

---

# Day 7 — PCB Completion and Nose Cone Construction
### ⏱️ 9 hours 5 minutes

I dedicated essentially the entire day to answering two major questions:

> **How do I build a solid PCB?**

and

> **How should I design the nose cone appropriately?**

---

## Part 1 — Orion Flight Computer PCB

Starting with the PCB, I got down to business.

I learnt countless new concepts, including:

- why **wider tracks** are useful for higher-current power connections
- the purpose of **copper pours**
- how **vias** connect separate PCB copper layers
- how to avoid creating an unmanageable **ratsnest**
- PCB **Design Rules Checks (DRC)**
- appropriate component spacing and placement
- silkscreen requirements
- thermal reliefs and copper islands

Vias were particularly interesting. I like to think of them as tiny **wormholes** that take an electrical connection from one side of the PCB to the other.

I spent a significant amount of time determining the optimal component layout.

<p align="center">
  
</p>

<p align="center">
  <em>Developing the component layout for the Orion Flight Computer PCB.</em>
</p>

I settled on this layout because placing the **Arduino in the centre** allowed the surrounding components to be positioned on either side according to the pins they needed to connect to.

I also designed a small logo for the **Orion Flight Computer** in the bottom-left corner of the PCB using Canva.

I searched for an image of the Orion constellation and modelled the decal around it, which seemed particularly fitting given the name.

### Troubleshooting

A significant portion of the session involved correcting earlier schematic and footprint mistakes.

Some pin labels on components such as the **BMP388** and **MicroSD Breakout Board+** differed slightly from their manufacturer's terminology.

Examples included:

- `3V3` → `3Vo`
- `SCL` → `SCK`
- `VCC` → `VIN`

Troubleshooting took up the majority of my time.

I'd estimate that finalising the PCB consumed approximately **7 of the 9 hours** spent on the project that day.

Some notable errors included:

- setting silkscreen text to **0.7 mm** when a larger size was preferable for manufacturing
- isolated **copper fill** regions
- inadequate thermal-relief connections
- overly wide tracks interfering with nearby pads
- silkscreen elements overlapping solder-mask regions

Eventually, the Design Rules Check was cleared.

<p align="center">
  
</p>

<p align="center">
  <em>The completed Orion Flight Computer PCB design.</em>
</p>

---

## Part 2 — Nose Cone Construction

After leaving CAD alone for a while, I finally decided it was time to tackle the nose cone.

I started out thoroughly confused because I initially attempted to navigate the process with very little assistance.

Long story short, I generated a curve based on the **Haack series**, inspired by the process demonstrated by the [Rocket Component Tools calculator](https://coleandreoli-rocket-component-tools-main-blwurh.streamlit.app/).

I then created horizontal and vertical construction lines representing:

- **30 mm radius**
- **180 mm nose-cone length**

The generated Haack-series profile was revolved around the central axis to produce the three-dimensional nose cone.

I then centred a two-dimensional circle on the flat end of the revolved shape and extruded it to create the **shoulder**, allowing the nose cone to fit inside the rocket's body tube.

This ultimately produced the first physical nose-cone prototype.

---

### End-of-Day Result

By the end of Day 7:

- ✅ Orion Flight Computer PCB layout completed
- ✅ PCB Design Rules Check resolved
- ✅ Custom Orion silkscreen logo created
- ✅ Nose cone model completed
- ✅ Nose cone prepared for 3D printing
- ✅ GitHub documentation brought up to date

The rest of the session was spent organising the GitHub repository and preparing the project for the next stage.

---

# Day 8 — Nose Cone Amendments and GitHub Overhaul
### ⏱️ 5 hours 55 minutes

Today was split between two things: continuing the nose cone design and giving the GitHub repository a fairly serious overhaul.

I spent an ungodly amount of time going through the repository, cleaning up folders, reorganising documentation, updating the BOMs, and generally trying to make the project understandable to someone other than myself.

The second half of the day was spent revisiting the nose cone.

The original nose cone itself was already functional, but the recovery system still needed a proper structural attachment point. I therefore began redesigning the shoulder to include an internal recovery structure.

The updated design incorporated:

- a hollow **2.5 mm shoulder wall**
- a **7.5 mm internal bulkhead**
- a reinforced central boss
- a **Ø6.4 mm recovery hole**
- additional internal space for the recovery hardware

The main difficulty was determining how the shock cord could realistically be attached without relying on a weak section of printed PLA.

I initially considered embedding an eye bolt into the print itself, but this quickly introduced a number of manufacturing problems that would need to be resolved later.

<p align="center">
  
</p>

<p align="center">
  <em>Development of the reinforced shoulder and internal recovery structure.</em>
</p>

By the end of the day, the nose cone was significantly closer to being a genuinely usable component rather than simply a hollow aerodynamic shell.

---

# Day 9 — Nose Cone Finalisation, Firmware and Simulation
### ⏱️ 6 hours 30 minutes

Today I spent hours moiling away at SolidWorks.

The focus was finally completing the structural side of the nose cone and recovery system.

I learnt how to:

- create and apply **fillets**
- build a central **boss structure**
- create reinforcing **ribs**
- use circular patterns around a central axis
- work with multiple solid bodies
- merge the shoulder and nose cone into one printable body
- prepare the model for slicing and support generation

The final recovery structure used:

- a **7.5 mm bulkhead**
- a **Ø20 mm central boss**
- four reinforcing ribs
- a **Ø6.4 mm central recovery hole**
- filleted rib roots to reduce sharp stress concentrations

One thing that caused a fair amount of pain was the recovery fastener.

My original plan was to insert a long eye bolt while the nose cone was printing. After looking at how close and how quickly the printer head travels above the active layer, I realised that having a large metal fastener protruding into the printing area was not a particularly intelligent idea.

I therefore moved toward using an **M6 RivNut** installed after printing. The existing Ø6.4 mm hole can be carefully enlarged to match the installation diameter of the selected RivNut, allowing an M6 eye fitting to be installed after the print is complete.

<p align="center">
  
</p>

<p align="center">
  <em>Nose Cone V2.</em>
</p>

### Firmware

I also started developing the firmware for the **Orion Flight Computer**.

Because the physical components have not yet been procured, I created a virtual prototype using **Wokwi**.

The simulation used:

- Arduino Nano
- MPU6050
- BMP180
- MicroSD card

The BMP180 is used only as a stand-in for the final BMP388 because Wokwi does not currently provide the BMP388 as a standard simulated component.

After a fair amount of troubleshooting with the SD libraries and SPI wiring, I successfully got the simulation to:

- initialise the MPU6050
- initialise the BMP180
- calculate relative altitude
- initialise the MicroSD card
- create a CSV file
- record simulated flight data
- output live measurements through the Serial Monitor

Being able to manipulate the simulated atmospheric pressure and watch Orion calculate a corresponding altitude change was probably one of the most satisfying software milestones of the project.

---

# Day 10 — SHIPMENT
### ⏱️ 1 hour 33 minutes

The project is finally in a state where I am comfortable shipping it.

Today was primarily spent tying everything together.

The GitHub repository was finalised with:

- project documentation
- CAD files
- PCB files
- fabrication documentation
- firmware
- Wokwi simulation files
- Bills of Materials
- construction guide
- project journal

I also finalised the most recent OpenRocket configuration.

The current simulation produces approximately:

| Parameter | Result |
|---|---:|
| Motor | Estes E12-4 |
| Apogee | 121.28 m |
| Maximum velocity | 38.74 m/s |
| Maximum acceleration | 67.35 m/s² |
| Maximum lateral distance | 28.84 m |
| Apogee time | 6.06 s |
| Recovery deployment | 6.44 s |
| Total flight time | 29.66 s |

I exported the OpenRocket flight data and used it to create an interactive HTML flight simulation so that the expected Odyssey flight can be viewed directly in a browser.

At this point:

- ✅ Rocket design complete
- ✅ Nose cone prototype complete
- ✅ Orion PCB design complete
- ✅ PCB fabrication files complete
- ✅ Orion firmware prototype complete
- ✅ Wokwi simulation functional
- ✅ OpenRocket simulation complete
- ✅ Interactive flight simulation complete
- ✅ BOM completed
- ✅ Construction guide completed
- ✅ GitHub repository completed

The remaining stages depend on funding and physical component procurement.

Once the required hardware arrives, the next major phase will consist of:

- PCB manufacturing
- component soldering
- USB bench testing
- sensor validation
- MicroSD logging validation
- avionics bay manufacturing
- full rocket assembly
- ground testing
- final flight testing

For now:

# **SHIPPED — AWAITING FUNDING**

<p align="center">
  
</p>

### Final Feedback Amendments

Following project review, two final amendments were incorporated:

- Rocket motors were removed from the funding request because propulsion hardware is treated separately from the fundable project components.
- Static-pressure vent holes were added to the nose-cone avionics design so that the BMP388 can measure external atmospheric pressure accurately.

These changes were incorporated into the project documentation and final design prior to funding submission.

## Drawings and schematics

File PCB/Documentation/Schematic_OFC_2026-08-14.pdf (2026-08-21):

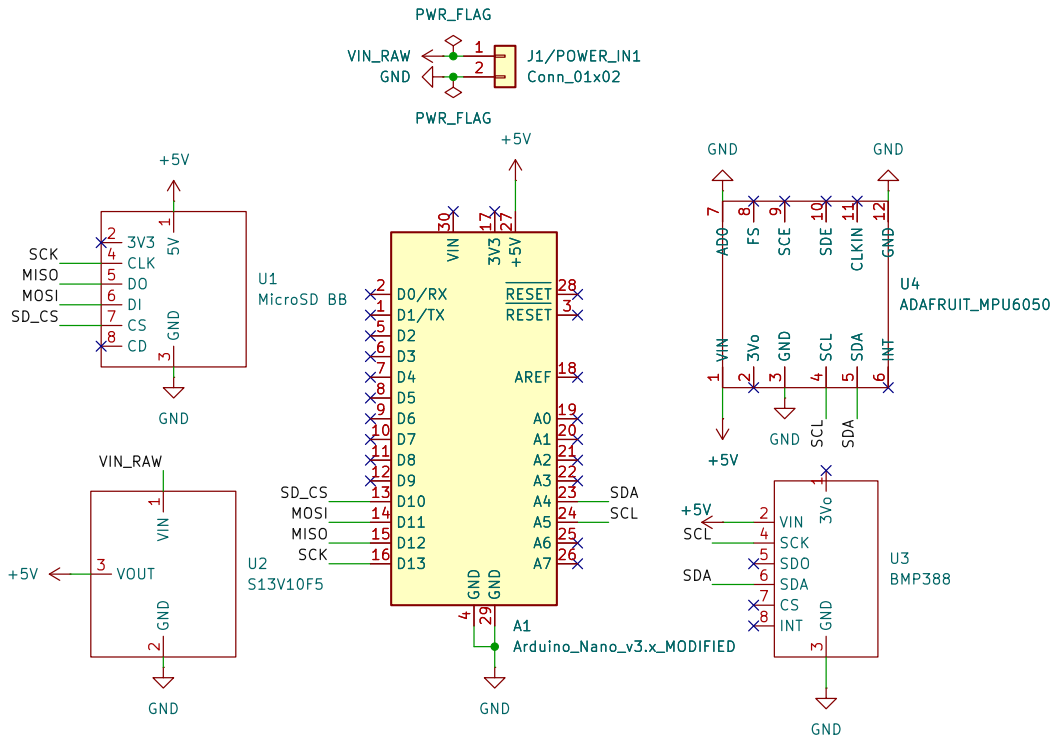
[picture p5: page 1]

8 SCE 9 SDE 10 CLKIN 11 GND 12 GND

8 SCE 9 SDE 10 CLKIN 11 GND 12 U4

3 CLK 4 DO 5 DI 6 CS 7 CD 8 U1MicroSD BB +5V GND
SCK

Size: A4 | Rev:
KiCad E.D.A. 10.0.5 | Id: 1/1

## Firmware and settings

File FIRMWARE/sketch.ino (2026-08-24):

// --------------------------------------------------
// THIS CAN BE INSERTED INTO WOKWI ASSUMING THAT THE WIRING FOR THE COMPONENTS WAS CARRIED OUT CORRECTLY
// --------------------------------------------------


#include <Wire.h>
#include <SPI.h>
#include <SdFat.h>

#include <Adafruit_MPU6050.h>
#include <Adafruit_Sensor.h>
#include <Adafruit_BMP085.h>

// --------------------------------------------------
// ORION FLIGHT COMPUTER
// Wokwi Prototype
//
// Simulated hardware:
// Arduino Nano
// MPU6050
// BMP180 (proxy for final BMP388)
// MicroSD card
// --------------------------------------------------


// ---------- Hardware ----------

Adafruit_MPU6050 mpu;
Adafruit_BMP085 bmp;

SdFat sd;
File flightFile;

const int SD_CS_PIN = 10;


// ---------- Logging ----------

const unsigned long SAMPLE_INTERVAL = 100;   // 10 Hz
const unsigned long FLUSH_INTERVAL = 1000;

unsigned long lastSample = 0;
unsigned long lastFlush = 0;


// ---------- Flight data ----------

float launchAltitude = 0.0;
float maximumAltitude = 0.0;


// --------------------------------------------------
// SETUP
// --------------------------------------------------

void setup() {

  Serial.begin(115200);

  delay(500);

  Serial.println();
  Serial.println("================================");
  Serial.println("   ORION FLIGHT COMPUTER");
  Serial.println("      WOKWI PROTOTYPE");
  Serial.println("================================");
  Serial.println();


  // ---------------- MPU6050 ----------------

  Serial.print("MPU6050: ");

  if (!mpu.begin()) {
    Serial.println("FAILED");
    stopSystem();
  }

  Serial.println("OK");

  mpu.setAccelerometerRange(MPU6050_RANGE_8_G);
  mpu.setGyroRange(MPU6050_RANGE_500_DEG);
  mpu.setFilterBandwidth(MPU6050_BAND_21_HZ);


  // ---------------- BMP180 ----------------

  Serial.print("BMP180:  ");

  if (!bmp.begin()) {
    Serial.println("FAILED");
    stopSystem();
  }

  Serial.println("OK");


  // Establish starting altitude

  launchAltitude = bmp.readAltitude();

  Serial.print("Reference altitude: ");
  Serial.print(launchAltitude);
  Serial.println(" m");


  // ---------------- SD CARD ----------------

  Serial.print("SD Card: ");

  if (!sd.begin(SD_CS_PIN, SD_SCK_MHZ(4))) {
    Serial.println("FAILED");
    stopSystem();
  }

  Serial.println("OK");


  // Create flight log

  flightFile = sd.open("FLIGHT.CSV", FILE_WRITE);

  if (!flightFile) {

    Serial.println("Could not create FLIGHT.CSV");
    stopSystem();
  }


  // CSV headings

  flightFile.println(
    "time_ms,"
    "altitude_m,"
    "pressure_pa,"
    "temperature_c,"
    "accel_x,"
    "accel_y,"
    "accel_z,"
    "gyro_x,"
    "gyro_y,"
    "gyro_z"
  );

  flightFile.flush();


  Serial.println();
  Serial.println("FLIGHT.CSV created.");
  Serial.println();
  Serial.println("Orion ready.");
  Serial.println();

  Serial.println(
    "TIME(ms) | ALT(m) | PRESSURE(Pa) | "
    "AX | AY | AZ"
  );
}


// --------------------------------------------------
// MAIN LOOP
// --------------------------------------------------

void loop() {

  unsigned long currentTime = millis();


  if (currentTime - lastSample >= SAMPLE_INTERVAL) {

    lastSample = currentTime;

    readAndLogSensors(currentTime);
  }


  // Periodically commit data to SD

  if (currentTime - lastFlush >= FLUSH_INTERVAL) {

    lastFlush = currentTime;

    flightFile.flush();
  }
}


// --------------------------------------------------
// READ SENSORS
// --------------------------------------------------

void readAndLogSensors(unsigned long timeMs) {

  sensors_event_t accel;
  sensors_event_t gyro;
  sensors_event_t temp;

  mpu.getEvent(&accel, &gyro, &temp);


  // ---------- Barometer ----------

  float pressure = bmp.readPressure();

  float temperature = bmp.readTemperature();

  float absoluteAltitude = bmp.readAltitude();

  // Relative altitude from starting position

  float altitude =
    absoluteAltitude - launchAltitude;


  // Record maximum altitude

  if (altitude > maximumAltitude) {
    maximumAltitude = altitude;
  }


  // ---------- Serial Monitor ----------

  Serial.print(timeMs);
  Serial.print(" | ");

  Serial.print(altitude, 2);
  Serial.print(" | ");

  Serial.print(pressure, 0);
  Serial.print(" | ");

  Serial.print(accel.acceleration.x, 2);
  Serial.print(" | ");

  Serial.print(accel.acceleration.y, 2);
  Serial.print(" | ");

  Serial.println(accel.acceleration.z, 2);


  // ---------- SD CARD ----------

  flightFile.print(timeMs);
  flightFile.print(',');

  flightFile.print(altitude, 2);
  flightFile.print(',');

  flightFile.print(pressure, 0);
  flightFile.print(',');

  flightFile.print(temperature, 2);
  flightFile.print(',');

  flightFile.print(accel.acceleration.x, 3);
  flightFile.print(',');

  flightFile.print(accel.acceleration.y, 3);
  flightFile.print(',');

  flightFile.print(accel.acceleration.z, 3);
  flightFile.print(',');

  flightFile.print(gyro.gyro.x, 4);
  flightFile.print(',');

  flightFile.print(gyro.gyro.y, 4);
  flightFile.print(',');

  flightFile.println(gyro.gyro.z, 4);
}


// --------------------------------------------------
// ERROR STATE
// --------------------------------------------------

void stopSystem() {

  Serial.println();
  Serial.println("ORION HALTED");

  while (true) {
    delay(1000);
  }
}

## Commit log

2026-08-13 Update README with PCB schematic and configuration info
    Added a schematic image and updated PCB configuration details.
2026-08-14 Update README.md
    Updated the KiCad schematic for the PCB so that it contains a power source and a buck-converter (evidence that it can be powered).
2026-08-14 Revise JOURNAL.md with detailed project insights
    Updated the JOURNAL.md to enhance descriptions and correct formatting. Added details about software usage and design considerations for the rocket prototype.
2026-08-16 Revise journal entries and add new content
    Updated Day 2 title and added Day 4 and Day 5 entries with details on KiCad and component selection.
2026-08-16 Refactor JOURNAL.md to remove duplicates and add entries
    Removed duplicate entries for Day 2 and Day 4, and added new entries for Day 4 and Day 5 detailing schematic design and improvements.
2026-08-16 Revise total time and document IMU schematic changes
    Updated total time spent and added details about the IMU schematic revision.
2026-08-16 Add Bill of Materials (BOM) file
2026-08-16 Add link to Bill of Materials in README
    Added a link to the Bill of Materials in the README.
2026-08-21 Add Bill of Materials for project components
2026-08-21 Revise BOM format and item details
    Updated the Bill of Materials (BOM) format and corrected item descriptions.
2026-08-21 Create PCB
2026-08-21 Add BOM details for components used in PCB
    [BOM.csv]
2026-08-21 Added Gerbers file for PCB
2026-08-21 Added the technical schematic for the PCB
2026-08-21 Added Schematic for the Orion Flight Computer
2026-08-21 Update JOURNAL with Day 7 activities
    Documented progress on PCB design and nose cone construction, including troubleshooting and layout decisions.
2026-08-21 Revise JOURNAL.md with time tracking and updates
    Updated journal entries with time spent on each day and detailed progress on rocket prototype development, including schematic design and component selection.
2026-08-23 Added drill maps for PCB
2026-08-23 Added Component Placement File for the PCB
2026-08-23 Added the KiCad Project File
2026-08-23 Added PCB visual
2026-08-23 Rename Untitled design (1).pdf to PCB_OFC_2026-08-23.pdf
2026-08-23 Add KiCad Schematic File
    [,.kicad_sch]
2026-08-23 Added KiCad PCB File
    [,.kicad_pcb]
2026-08-23 Added .drl file
    [,.drl]
2026-08-23 Update JLCPCB manufacturing guide with new notes
    Added notes on PCB color change and updated final checklist for JLCPCB manufacturing guide.
2026-08-24 Added Nose Cone CAD File
    [NoseCone.SLDPRT]
2026-08-24 Added STEP File
    [NoseCone.STEP]
2026-08-24 Add documentation for Orion flight computer simulation
    This document outlines the prerequisites, features, and operational flow for the Orion flight computer simulation using Wokwi. It details the components used, how to run the simulation, and the expec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
2026-08-24 Update PCB reference in README.md
2026-08-24 Add Orion flight computer sketch with sensor logging
    This file contains the implementation of the Orion flight computer using various sensors and an SD card for data logging.
2026-08-24 Add OrionFlightComputer BOM file
    [OrionFlightComputer.csv]
2026-08-24 Add Rocket Hardware BOM with specifications
2026-08-24 Revise cost estimates and item details in README
    Updated the estimated total cost and item list for the Odyssey Rocket Bill of Materials.
2026-08-24 Added PCB Decal to Assets
2026-08-24 Update GUIDE.md for accuracy and clarity
    Corrected links and terminology in the guide, updated dimensions and specifications for various components, and clarified instructions for assembly and testing.
2026-08-24 Complete project documentation and prepare for shipment
    Finalized project documentation, CAD, PCB, firmware, and simulation files in the GitHub repository. Completed the rocket design and nose cone prototype, and prepared for shipment pending funding.
2026-08-24 Added BOM.csv
    [BOM.csv]
2026-08-25 Added BOM.csv file
    [BOM (2).csv]
2026-08-25 Rename BOM (2).csv to BOM.csv
    [BOM.csv]
2026-08-25 Revise BOM for rocket hardware with new parts
    Updated the bill of materials to include new components and specifications for the rocket hardware.
2026-08-27 Revise project cost and note rocket motor supply
    Updated estimated total project cost and added note about rocket motor supply.
2026-08-27 Removed Estes Motor from Hardware Section
2026-08-27 Update README with detailed features and compliance info
    Enhanced the description of the Orion Flight Computer and its features, including details about the nose-cone-mounted PCB and static-pressure vent holes. Updated compliance details with Western Austr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
2026-08-27 Revise Orion Flight Computer and avionics bay sections
    Updated sections related to the Orion Flight Computer installation and avionics bay housing. Added details on pressure vent holes and modified the structure of the guide for clarity.
